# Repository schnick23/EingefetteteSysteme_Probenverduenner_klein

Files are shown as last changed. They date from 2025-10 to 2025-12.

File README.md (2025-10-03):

# Probenverdünner (Raspberry Pi + Flask)

Web-gesteuerter Probenverdünner für die Uni: Flask-Webserver auf einem Raspberry Pi steuert Pumpen, Ventile und Sensoren über GPIO. Enthält eine Hardware-Abstraktionsschicht (HAL) sowie eine Mock-Implementierung für Entwicklung ohne Pi.

## Features (MVP)
- Flask-Webserver mit REST-API und einfacher Web-UI
- Hintergrund-Tasks (Start/Stop von Verdünnungsabläufen)
- HAL: `controller` Interface, `rpi_impl` (GPIO), `mock_impl` (Simulation)
- SQLite für Protokolle (später) und Basis-Konfiguration
- systemd-Unit für Autostart auf dem Raspberry Pi

## Struktur
```
app/
  __init__.py
  main.py          # App-Factory & Serverstart
  api.py           # REST-Endpoints
  templates/
    index.html     # UI
  static/
    app.js
    style.css
  hw/
    controller.py  # Interfaces
    rpi_impl.py    # GPIO-Implementation (Pi)
    mock_impl.py   # Mock für Entwicklung
  tasks/
    runner.py      # Hintergrund-Tasks
  models.py        # (später) DB-Modelle
  config.py        # Konfig
deploy/
  raspberrypi.service  # systemd Unit
scripts/
  install_pi.sh
requirements.txt
```

## Schnellstart (lokal, ohne Pi)
```bash
python3 -m venv .venv
source .venv/bin/activate
pip install -r requirements.txt
FLASK_ENV=development python -m app.main
```
Öffne http://localhost:5000

Mock-HAL ist Standard. Umschalten auf RPi via Environment `HW_BACKEND=rpi`.

## Deployment auf Raspberry Pi (Kurz)
```bash
git clone <repo>
cd EingebetteteSysteme_Probenverduenner_klein
bash scripts/install_pi.sh
# systemd unit anpassen & aktivieren
env HW_BACKEND=rpi python -m app.main
```

## Sicherheit
- Standardmäßig keine Auth – im Labor-Netz betreiben oder Basic-Auth / Token ergänzen.
- GPIO initialisiert sichere Zustände, Fehler stoppen Tasks.

## Nächste Schritte
- Auth / Token
- Logging in Datei + Rotierung
- Echte Sensor-/Ventilsteuerung
- Verdünnungslogik (Parametrisierte Sequenzen)

## Lizenz
MIT

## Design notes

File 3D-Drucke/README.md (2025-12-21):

# 3D-Drucke

## Allgemeines

Alle 3D-Drucke für den Probenverdünbner wurden mit "ELEGOO PLA Filament 1.75mm Schwarz" gedruckt. Im Einsatz war ein Ender 3 Pro sowie ein Bambu Lab P1S.
Die Modellierung wurde in Autodesk Fusion vorgenommen, daher sind auch Fusion-Dateien mit hochgeladen, falls Änderungen an Maßen etc. gemacht werden sollen.

## Besonderheiten

Fast alle 3D-Modelle können direkt und ohne Unterbrechung gedruckt werden, bei wenigen ist es sinnvoll Support zu aktivieren. Alle Halterungen die in die Nut des Aluprofils eingeklickt werden können (u.a. Kaltgerätebuchse, Ethernet, Kabel) sind zusammengefasst in einer Fusion-Datei, jedoch als einzelne .stl-Dateien direkt druckbereit.

Eine weitere Besonderheit bildet die SpritzenkopfHalterung03.stl. In dieser Halterung sind 2 Hohlräume für Sechskant-M8-Muttern modelliert, die eingelegt werden müssen und dann im Druck "verschwinden". Um dies zu machen muss im Slicer eine Pause eingefügt werden auf der Höhe wenn der Hohlraum komplett gedruckt wurde.

## Fragen und Kontakt

Sollte es zu den Dateien oder zum 3D-Druck Fragen geben gerne per Mail an nick.schroeder@nordakademie.de oder an die anderen Teammitglieder deren Mailadressen auch auf dem Benutzerhandbuch stehen

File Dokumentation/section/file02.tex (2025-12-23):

\section{Sicherheit}
\subsection{Allgemeine Sicherheitshinweise}
Der entwickelte Probenverdünner dient ausschließlich dem zuvor beschriebenen Zweck (\autoref{ZweckDesGeraets}) der Verdünnung von Proben. Um zu prüfen, ob der Pinkler die Anforderungen der geplanten Verdünnung erfüllt, kann in \autoref{TechnischeSpezifikationen} nachgeschaut werden. Zudem sollte das Gerät nur von eingewiesenem Personal, welches entweder, durch das Lesen von diesem Dokuments oder durch eine Einweisung von bereits geschultem Personal, sich mit dem System vertraut gemacht hat. Die Technik des Geräts ist komplex und empfindlich und sollte daher nicht verändert werden. \\

Es ist wichtig, dass die Bedienungsanleitung vor der Inbetriebnahme vollständig gelesen wird. Des Weiteren ist das Gerät, nach den in \autoref{WartungUndReinigung} beschriebenen Methoden zu überprüfen, warten und reinigen. \\

Bei Schäden oder Fehlfunktionen ist das System sofort außer Betrieb zu nehmen. Hierbei ist der Not-Aus-Knopf zu betätigen(vorne rechts auf der Platte). Wie dieser zu bedienen ist folgt im nächsten Kapitel \nameref{ElektrischeSicherheitshinweise}.\\

Es dürfen nur Chemikalien verwendet werden, die mit den Materialien des Gerätes kompatibel sind (vgl. \autoref{tab:Bauteile}).

\subsection{Elektrische Sicherheitshinweise}\label{ElektrischeSicherheitshinweise}
Der Pinkler wird über ein 230V Netzteil angeschlossen und mit Strom versorgt. Nahezu die komplette Elektronik des Geräts befindet sich auf der Unterseite der Bodenplatte, siehe \autoref{fig:unten}. 

\begin{figure}[H] % r = rechts, l = links
    \centering
    
    \caption{Elektronik auf der Unterseite des Probenverdünners}
    \label{fig:unten}
\end{figure}

Deswegen sollte dieser vorsichtig auf einem stabilen, und noch wichtiger, trockenem Untergrund platziert werden. Es sollte außerdem zu jeder Zeit darauf geachtet werden, dass keine Flüssigkeiten verschüttet werden; sowohl über, als auch neben dem Gerät, da dieses, zusätzlich zu der offenen Elektronik, auch Löcher für die Kabel einiger Geräte im Boden hat.\newpage

Sollte es dazu kommen, dass der Probenverdünner im laufenden Betrieb auf einen unerwarteten Fehler stößt oder beschädigt wird, ist sofort der Not-Aus-Schalter zu tätigen, siehe \autoref{fig:notaus}. 

\begin{figure}[H] % r = rechts, l = links
    \centering
    
    \caption{Not-Aus des Probenverdünners}
    \label{fig:notaus}
\end{figure}

Nachdem dieser gedrückt wurde fährt sich sämtliche Elektronik des Geräts runter und alles bleibt dort stehen wo es ist. Um das Gerät nach dem Notfall wieder einzuschalten, muss der Not-Aus-Knopf einmal nach rechts gedreht werden.\\

Danach fährt das Gerät wieder hoch und der Zugriff auf die grafische Oberfläche ist möglich. Dort findet man den Button \textbf{Reset}, durch welchen der Probenverdünner zurück an die Nullpositionen fährt und alles resetet. Erst danach kann das Gerät wieder normal genutzt werden, siehe \autoref{fig:start}.\\

\begin{figure}[H] % r = rechts, l = links
    \centering
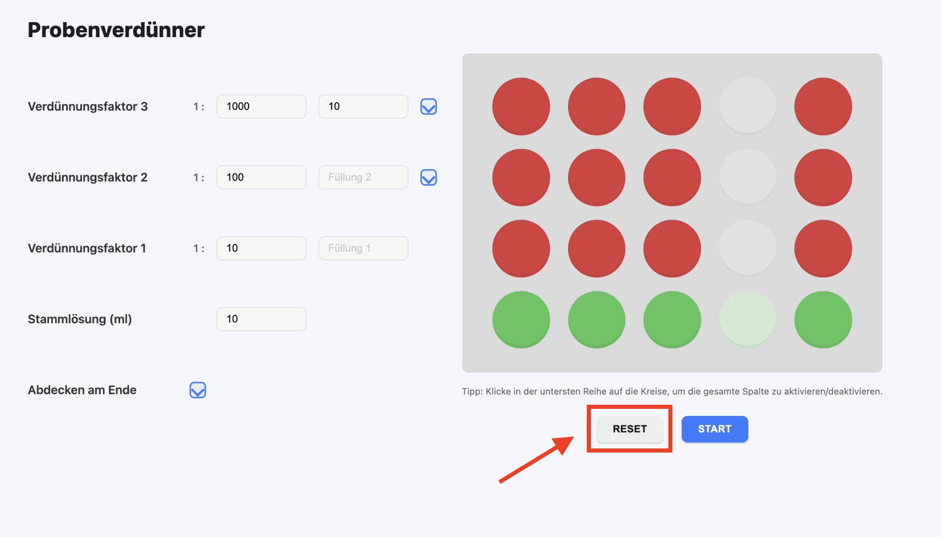
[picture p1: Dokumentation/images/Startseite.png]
    
    \caption{GUI Startseite Reset Button}
    \label{fig:start}
\end{figure}

\subsection{Mechanische Sicherheitshinweise}\label{MechanischeSicherheitshinweise}
Aus Kostengründen wurden die Füße sowie die Steckerhalter für Netzwerk und Strom 3D-gedruckt. Diese sind zwar stabil aber können bei unvorsichtiger Benutzung brechen. Sollte dies auftreten, können die nötigen Pläne, um diese erneut zu drucken, im GitHub unter dem Ordner \textit{3D-Drucke} gefunden werden. \\

Es empfielt sich das Gerät nicht zu nutzen, solange die Teile noch nicht wieder ausgetauscht wurden. \\

Leider ist der gewählte Motor, welcher den Hubtisch antreibt, nicht stark genug, um die Last der Proben zusammen mit den Widerständen, die durch das Gewinde und die Führstangen des Hubtisches entstehen, zu bewegen. Daher wurde ein Expandierseil mit Haken zur Unterstützung an dem Rahmen und dem Hubtisch befestigt.\\

Während des gesamten Durchlaufs darf nichts in dem Pinkler landen. Insbesondere der Hubtisch und die Linearführung des Spritzkopfes stellen eine Quetschgefahr dar. Deshalb sollten lange Haare, Kleidung oder Schmuckstücke von den beweglichen Teilen ferngehalten werden, um ein Verfangen zu vermeiden. \\

Zudem ist der Probenverdünner nicht für hohe Lasten geeignet. Das Gerät sollte somit nicht als Ablage oder Stütze genutzt werden.

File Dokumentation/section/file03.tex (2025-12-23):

\section{Technische Spezifikationen}\label{TechnischeSpezifikationen}
\subsection{Systemübersicht}\label{Systemuebersicht}
Die folgenden Kapitel bieten einen Überblick über die Hauptkomponenten der Maschine, deren Funktion und ihre technischen Möglichkeiten.
\subsubsection{Steuerungseinheit}
Die gesamte Technik wird mithilfe von zwei Netzteilen, ein 12-Volt- und ein 24-Volt-Netzteil, mit Strom versorgt. An das 12 Volt Netzteil ist wiederum ein Spannungswandler, welcher die passende Spannung von 5 Volt an den Raspberry Pi (Raspberry Pi 4 Model B) weiterleitet. Dieser fungiert als zentrale Steuerungseinheit. In ihm steckt eine SD Karte, auf der die Software gespeichert ist, welche die grafische Oberfläche erzeugt, sowie die Steuerungslogik, mit welcher die anderen Komponenten angesteuert werden. Eine dieser anderen Komponenten ist das Acht-Kanal-Relais, über welches die Pumpen einzeln oder zusammen angesteuert und auch hin und zurück pumpen können. Weiterhin sind an dem Pi die Driver der Stepper-Motoren angeschlossen.\\

In \autoref{fig:unten} sind alle Komponenten der Steuerungseinheit zu sehen.
\subsubsection{Linearantrieb}
Im vorherigen Kapitel wurde ein Linearmotor erwähnt, dieser ist fest an dem Linearantrieb angebracht, siehe \autoref{fig:linear}, und sorgt dafür das der Spritzkopf in Y-Richtung, entlang der großen Gewindestange, bewegt werden kann. Der Linearantrieb fährt mit einer Geschwindigkeit von maximal 50mm/s, und erreicht die gesetzten Positionen auf den Zehntelmilimeter genau. \newline

\begin{figure}[H] % r = rechts, l = links
    \centering
    
    \caption{Linearantrieb des Probenverdünners}
    \label{fig:linear}
\end{figure}
\newpage
\subsubsection{Pumpen}
Insgesamt werden in dieser Maschine fünf Pumpen verwendet, die das Verdünnungsmittel mit einem maximalen Fehler von 0,5\% auf 10ml aufziehen. Diese Pumpen werden durch das Relais-Modul gesteuert, sodass jede Pumpe einzeln angesteuert werden kann. Dies ermöglicht es einzelne Spalten zu deaktivieren. Außerdem können dadurch die minimale Abweichungen pro Pumpe ausgleichen. Im Betrieb wird jeweils in Schritten von 1ml gepumpt. Alle Pumpen starten dabei zeitgleich, aber enden zeitversetzt, sodass jede Pumpe genau 1ml gepumpt hat. An jeder Pumpe sind 2 Schläuche befestigt. Einer davon ist fest verbunden mit dem Spritzenkopf, der jeweils andere (also 5 verbleibende Schläuche) müssen vor Start des Programms in die Schottflasche gelegt werden. Diese muss zu jeder Zeit einen Mindestfüllstand von 50ml haben. \newline

\begin{figure}[H] % r = rechts, l = links
    \centering
    
    \caption{Pumpen des Probenverdünners}
    \label{fig:pumpen}
\end{figure}
\newpage
\subsubsection{Spritzenkopf}
Der Spritzenkopf ist an einem Aluprofil befestigt, welches zwischen zwei Linearführung befestigt ist. Er wird von dem Linearantrieb betrieben. An ihm sind dazu noch fünf Spritzen und Schläuche montiert, welche die Falcontubes befüllen. Die Spritzen werden über einen Steppermotor und einem 3D-gedrucktem Konstrukt gleichmäßg und gleichzeitig aufgezogen, sodass fünf oder weniger Proben gleichzeitig befüllt oder entnommen werden können. Die Spritzen arbeiten mit einem maximalen Fehler von 3\%. Zuletzt ist an dem Spritzkopf noch eine Platte befestigt, welche am Ende einer Verdünnung die Falcontubes bedecken kann.\newline

\begin{figure}[H] % r = rechts, l = links
    \centering
    
    \caption{Spritzen und Spritzenköpfe des Probenverdünners}
    \label{fig:spritzenkopf}
\end{figure}

\subsubsection{Hubtisch}
Auf dem Hubtisch befinden sich der Falcon-Tube-Ständer, ein Reinigungsbehälter, sowie ein Abfallbehälter. Im Normalfall würde dieser manuell über ein Gewinde betätigt werden. In dem Probenverdünner wird jedoch die Hoch-Runter-Bewegung über ein Stepper-Motor automatisiert und kann verschieden Positionen anfahren. Wie zuvor in \autoref{MechanischeSicherheitshinweise} erwähnt musste eine Expandierseil als zusätzliche Unterstützung des Motors implementiert werden.

\begin{figure}[H] % r = rechts, l = links
    \centering
    
    \caption{Hubtisch des Probenverdünners von vorne}
    \label{fig:Hubtischvorne}
\end{figure}

\subsubsection{Technische Möglichkeiten}\label{TechnischeMoeglichkeiten}
Der Pinkler ist in der Lage 15 Proben in unter 25 Minuten zu befüllen. Der maximale Verdünnungsfaktor beträgt 1/1000. In diesem Fall lassen sich fünf Proben verdünnen. Bei einem Verdünnungsfaktor von unter 1/100 lassen sich zehn verdünnte Proben befüllen und bei einem Verdünnungsfaktor von unter 1/10, 15. Alle Verdünnungsverhältnisse, die nicht vom Probenverdünner umgesetzt werden können, werden durch die Software abgefangen.

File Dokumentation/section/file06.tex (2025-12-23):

\section{Funktionsweise}
\subsection{Grundprinzip der Probenverdünnung}
Um eine Verdünnung von bis zu 1000-fach zu erreichen, nutzt der Probenverdünner das Prinzip der seriellen Verdünnung, bei dem eine konzentrierte Probe schrittweise mit einem Verdünnungsmittel gemischt wird, um die gewünschte Endkonzentration zu erreichen. Dabei werden präzise Mengen der Probe und des Verdünnungsmittels dosiert und in den nächsten Falcontube zusammengeführt. \\

Bei einer Verdünnung bis 10-fach wird direkt aus der Stammlösung entnommen und in die Zielprobe gegeben. Für höhere Verdünnungen wird die Probe in mehreren Schritten verdünnt, wobei jede Stufe eine weitere Verdünnung darstellt. Die zweite Reihe kann bis zu 100-fach verdünnen, indem sie die erste verdünnte Probe weiterverarbeitet. Die dritte Reihe ermöglicht schließlich eine Verdünnung bis zu 1000-fach, indem sie die bereits verdünnte Probe erneut weiter verdünnt. Auch ist es möglich, dass alle Reihen die diesselbe Verdünnung erreichen, solange genügend Stammlösung dafür vorhanden ist. Ebenfalls können auch zwei Reihen dasselbe Verdünnungsverhältnis haben und die dritte ein unterschiedliches. Verdünnungsverhältnisse, die nicht erreicht werden können, werden von der Software blockiert, um eine fehlerhafte Probenvorbereitung zu vermeiden.
\newpage
\subsection{Ablauf eines Verdünnungsvorgangs}
\begin{figure}[h!]
    \centering
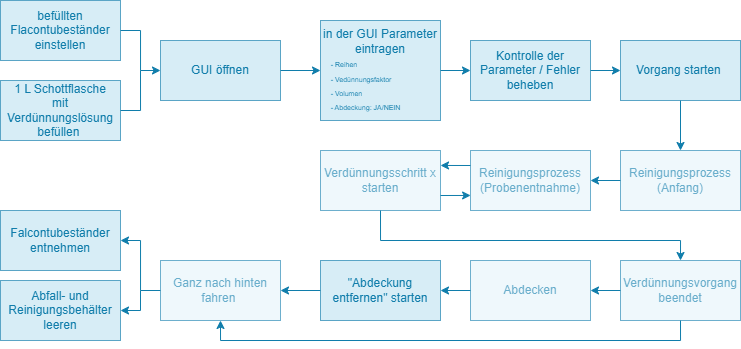
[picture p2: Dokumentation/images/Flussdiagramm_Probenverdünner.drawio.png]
    
    \caption{Ablaufdiagramm}
    \label{fig:Ablaufdiagramm}
\end{figure}

Anhand des Ablaufdiagramms in \autoref{fig:Ablaufdiagramm} wird der generelle Ablauf eines Verdünnungsvorgangs beschrieben. Zunächst muss der Falcontubeständer, die Schottflasche ggf. der Abfall- und der Reinigungsbehälter platziert werden, wie in \autoref{fig:Hubpositionierung}, \autoref{fig:Schottflaschepositionierung} und \autoref{fig:Falcontubespositionierung} zu sehen. 

\begin{figure}[H]
    \centering
    \begin{minipage}[t]{0.6\textwidth}
        \centering
        
        \caption{Positionierung der Komponenten auf dem Hubtisch}
        \label{fig:Hubpositionierung}
    \end{minipage}\hfill
    \begin{minipage}[t]{0.35\textwidth}
        \centering
        
        \caption{Positionierung der Schottflasche}
        \label{fig:Schottflaschepositionierung}
    \end{minipage}\hfill
\end{figure}

\begin{figure}[H]
    \centering
    
    \caption{Positionierung der Falcontubes}
    \label{fig:Falcontubespositionierung}
\end{figure}

Danach werden die benötigten Daten in der grafischen Oberfläche eingegeben. Dazu gehört die $"$Probenspalten-$"$ und $"$Probenreihen$"$-Auswahl, das gewünschte Verdünnungsverhältnis für jede Probe, sowie die Volumina der Stammlösungen und die gewünschten Endvolumina, siehe \autoref{fig:GUIerklaerung}. 

\begin{figure}[h!]
    \centering
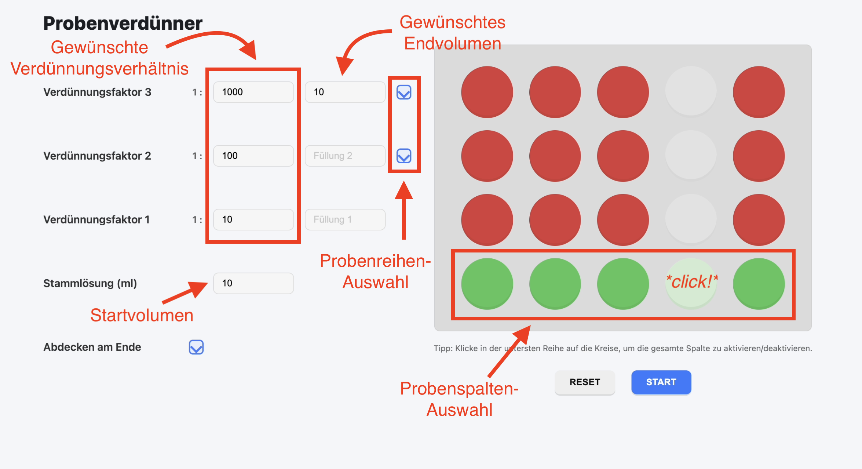
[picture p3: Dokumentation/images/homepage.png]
    
    \caption{GUI Startseite zur Eingabe der Verdünnungsparameter}
    \label{fig:GUIerklaerung}
\end{figure}

Nach der Eingabe der Daten und der Platzierung der Probenbehälter im Gerät, wird der Verdünnungsvorgang gestartet. Das System fährt zunächst die Startposition an und führt eine initiale Reinigung mit der Verdünnungslösung durch, um sicherzustellen, dass alle Schläuche und Spritzen frei von Verunreinigungen sind. \\

Daraufhin findet die Zwischenreiningung statt, indem die Spritzen die zu verdünnende Lösung plus 0.5ml aufziehen und in den Abfallbehälter entsorgen. Anschließend beginnt der eigentliche Verdünnungsschritt, bei dem die Proben entsprechend den eingegebenen Daten verdünnt werden. \\

Während des Prozesses werden auch zwischendurch Reinigungsschritte durchgeführt, um Kreuzkontaminationen zu vermeiden. Dieser Vorgang wird wiederholt, bis die letzte Verdünnung erreicht wurde. \\

Am Ende des Verdünnungsvorgangs erfolgt eine Entleerung, bei der alle Schläuche in die entgegesetze Pumprichtung Luft aufziehen. \\

Optional wird der Falcontubeständer abgedeckt, um die Proben vor Verdunstung oder Verunreinigung zu schützen. \\

Falls die Abdeckung nicht erfolgt, fährt der Spritzenkopf nach hinten in seine Anfangsposition und die Proben können manuell entnommen werden. \\

Sollten die Falcuntubes abgedeckt worden sein, muss auf der Website der Abdeckungsentfernen-Vorgang gestartet werden, siehe \autoref{fig:GUIabdeckungentfernen}, bevor die Proben entnommen werden können.

\begin{figure}[H]
    \centering
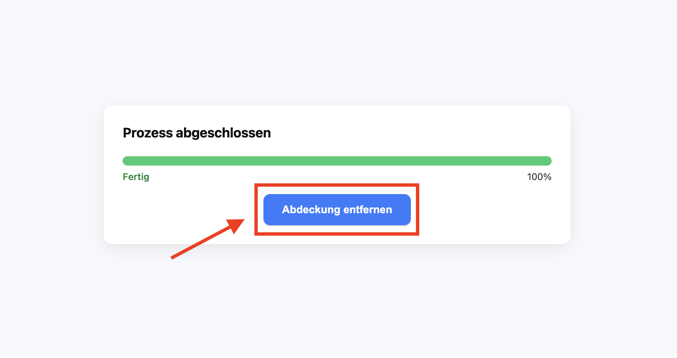
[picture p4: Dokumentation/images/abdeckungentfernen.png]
    
    \caption{GUI Abdeckungsentfernen Seite}
    \label{fig:GUIabdeckungentfernen}
\end{figure}

Zuletzt sollten der Abfall- und der Reinigungsbehälter geleert werden, um das Gerät für den nächsten Einsatz vorzubereiten.\\

Wurde der Prozess durch den Not-Aus unterbrochen, muss das System zunächst durch Drücken des Reset-Buttons in der grafischen Oberfläche zurückgesetzt werden, siehe \autoref{fig:start}. Danach kann der Ablauf von Anfang an durchgeführt werden.

\newpage
Im folgenden werden noch Ablaufdiagramme der Initialreinigung, der Zwischenreinigung und des Verdünnungsvorgangs dargestellt. Dabei ist die Reihe i, wo die Probenverdünnung stattfinden soll, und die Position wie im Code bestimmt, genauer:
\begin{itemize}
    \item \textbf{Position 1:} Abdeckungsposition
    \item \textbf{Position 2:} Reihe 1 (Stammlösung)
    \item \textbf{Position 3:} Reihe 2
    \item \textbf{Position 4:} Reihe 3
    \item \textbf{Position 5:} Reihe 4
    \item \textbf{Position 6:} Abfallbehälter
    \item \textbf{Position 7:} Reinigungsbehälter
    \item \textbf{Position 8:} Startposition (Home-Position)
\end{itemize}

\FloatBarrier
\begin{figure}[h!]
    \vspace{10mm}
    \centering
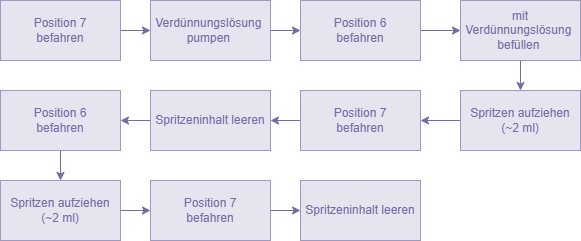
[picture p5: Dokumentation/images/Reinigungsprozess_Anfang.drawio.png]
    
    \caption{Ablaufdiagramm der Initialreinigung}
    \label{fig:AblaufdiagrammInitialreinigung}
\end{figure}

\begin{figure}[h!]
    \vspace{10mm}
    \centering
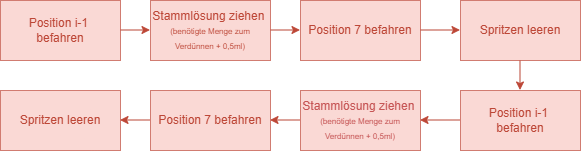
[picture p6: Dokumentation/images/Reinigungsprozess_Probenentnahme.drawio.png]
    
    \caption{Ablaufdiagramm der Zwischenreinigung}
    \label{fig:AblaufdiagrammZwischenreinigung}
\end{figure}

\begin{figure}[h!]
    \vspace{10mm}
    \centering
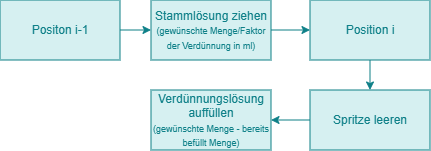
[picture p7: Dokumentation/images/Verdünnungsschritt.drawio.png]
    
    \caption{Ablaufdiagramm des Verdünnungsvorgangs}
    \label{fig:AblaufdiagrammVerdünnungsvorgang}
\end{figure}

\FloatBarrier

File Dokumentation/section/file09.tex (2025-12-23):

\section{Technische Dokumentation (Anhang)}
\subsection{Schaltplan}
\vspace{-0.8cm}
\begin{figure}[H]
    \centering
    
    \vspace{-0.75cm}
    \caption{Übersicht Schaltplan Probenverdünner}
    \label{schaltplan}
\end{figure}

\subsection{3D-Druck-Pläne}
Alle 3D-Druck-Pläne sind unter dem Ordner \href{https://github.com/schnick23/EingefetteteSysteme_Probenverduenner_klein/tree/main/3D-Drucke}{\textit{3D-Drucke}} im GitHub-Repository zu finden.

\subsection{Stückliste} \label{Materialien}
In der folgenden Tabelle sind alle im Probenverdünner verwendeten Materialien und deren Eigenschaften aufgelistet. 

\begin{longtable}{|l|l|}
        \caption{Stückliste des Probenverdünners}
        \label{tab:Bauteile}\\
        \hline
        \textbf{Bauteil} & \textbf{Bemerkungen} \\

        \hline
        \multicolumn{2}{|l|}{\textbf{Gehäuse}}\\
        \hline
        Aluprofil & 30x30mm; Länge: 440mm, 550mm; NUT 8; B-Typ\\
        Aluprofilinnenverbinder & NUT 8 \\
        Nutensteine & NUT 8 \\
        Aluplatte & 500x500mm \\

        \hline
        \multicolumn{2}{|l|}{\textbf{Linearführung}}\\
        \hline
        Linearantrieb & NEMA 23 Schrittmotor\\
        Schrittmotortreiber TB6600 & Für den NEMA 23 Schrittmotor\\
        Linearschienen & \\

        \hline
        \multicolumn{2}{|l|}{\textbf{Pumpen}}\\
        \hline
        Peristaltikpumpen & ID: 1mm, AD: 3,3mm; 12V 1,5A\\
        Relais Modul & DC 12V, 8 Kanal \\
        Schläuche & ID: 3mm, AD: 5mm; Platinvernetztes Silikonmaterial \\

        \hline
        \multicolumn{2}{|l|}{\textbf{Spritzen}}\\
        \hline
        NEMA 17 Schrittmotor & \\
        Schrittmotortreiber TMC2209 & Für den Schrittmotor NEMA 17\\
        Spritzen & 5ml; Luer-Lock-Spritzen\\
        Spritzenköpfe & 117mm; 18G\\
        Wellenkupelung & ID: 5mm und 8mm \\

        \hline
        \multicolumn{2}{|l|}{\textbf{Hubtisch}}\\
        \hline
        Hubtisch & 200x200mm; Hubhöhenbereich: 85-280mm; Max. 15kg\\
        NEMA 17 Schrittmotor & \\
        Schrittmotortreiber TMC2209 & Für den Schrittmotor NEMA 17\\
        Wellenkupelung & ID: 5mm und 8mm \\
        Expandierseil & Mit Haken; 0,6m lang \\

        \hline
        \multicolumn{2}{|l|}{\textbf{Sonstige Hardware}}\\
        \hline
        Not-Aus Knopf & \\
        Raspberry Pi 4 Model b & \\
        Endtaster & 125V 1A PDT-Grenzwert-Mikroschalter \\
        Netzteile & 12V 10A 120W; 24V 6A 150W \\
        Converter & 12V auf 5V 3A \\
        Schrauben & Dieverse Größen und Längen \\
        Muttern & Diverse Größen\\
        Litzen & Diverse Längen und Querschnitte \\
        \hline
\end{longtable}

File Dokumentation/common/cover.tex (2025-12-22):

\begin{titlepage}
\newgeometry{top=2cm, bottom=2cm, left=2cm, right=2cm}

%\definecolor{color_30879}{rgb}{0,0.12549,0.376471}

\newcommand{\stitle}{\fontsize{14}{1}\selectfont\color{NAKblue}}
\newcommand{\btitle}{\fontsize{16}{1}\selectfont\color{NAKblue}}

\centering
    %% Logo oben
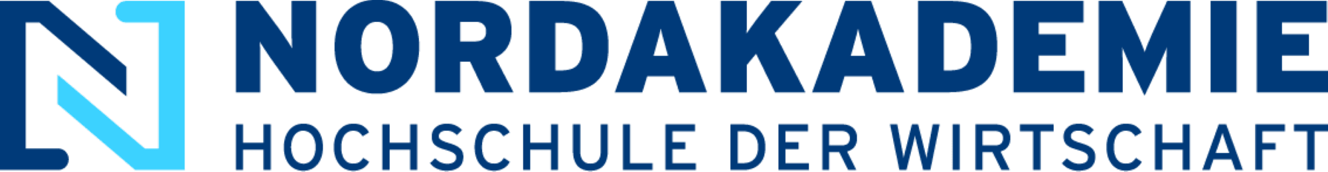
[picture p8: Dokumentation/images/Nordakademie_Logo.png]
    
    \vspace{20mm}

    \begin{spacing}{2}
        {\textbf{\fontsize{20}{1}\selectfont\color{NAKblue} Handbuch:}}\par
        {\textbf{\fontsize{18}{1}\selectfont\color{NAKblue} kleiner Probenverdünner}}\par
        \vspace{15mm}
        \textbf{{\btitle Erarbeitet von:}}\par
        {\stitle Leyna Haardt (leyna.haardt@nordakademie.de), Matrikelnummer: 12985}\par
        {\stitle Anastasia Klat (anastasia.klat@nordakademie.de), Matrikelnummer: 13275}\par
        {\stitle Max Meteling (max.meteling@nordakademie.de), Matrikelnummer: 13209}\par
        {\stitle Nick Schröder (nick.schroeder@nordakademie.de), Matrikelnummer: 13083}\par
        {\stitle Malte Wendeler (malte.wendeler@nordakademie.de), Matrikelnummer: 13105}\par
        {\stitle Studiengang: Technische Informatik}\par
        {\stitle Zenturie: T23a}\par
        \vspace{10mm}
        \textbf{{\btitle Eingebettete Systeme}}\par
        {\stitle Dozent und Prüfer:}\par
        {\stitle Prof. Dr. phil. nat. habil. Jan Haase}\par
    \end{spacing}

\renewcommand\thefootnote{}
\footnotetext{
  Zur besseren Lesbarkeit wird in dieser Hausarbeit das generische Maskulinum verwendet. Die in dieser Arbeit verwendeten Personenbezeichnungen beziehen sich - sofern nicht anders kenntlich gemacht - auf alle Geschlechter.
}

\end{titlepage}

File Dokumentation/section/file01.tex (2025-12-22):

\section{Einleitung}
\subsection{Zweck des Geräts}\label{ZweckDesGeraets}
Das vorliegende Gerät \textit{"Der Pinkler"} wurde im Rahmen eines Projektes, in Kooperation mit der Technischen Universität Bergakademie Freiberg, in dem Modul Eingebettete Systeme der NORDAKADEMIE, von den Studenten Leyna Haardt, Anastasia Klat, Max Meteling, Nick Schröder und Malte Wendeler entwickelt. Der Pinkler dient der präzisen und automatisierten Verdünnung von Proben in einem Chemielabor.
\subsection{Zielgruppe der Anleitung}
Diese Anleitung richtet sich an Laborpersonal und Techniker, die das Gerät bedienen, warten und gegebenenfalls reparieren müssen. Vorkenntnisse im Umgang mit Laborgeräten und grundlegende technische Kenntnisse sind von Vorteil.
\subsection{Kurzbeschreibung des Systems}
Das System besteht aus mehreren Hauptkomponenten, darunter ein mechanisches Gestell mit Achsen für die Bewegung eines Spritzkopfes, mehrere Pumpen zur Flüssigkeitsförderung, eine zentrale Steuerungseinheit zur Automatisierung der Prozesse, sowie eine grafische Oberfläche zur Bedienung des Geräts. Dadurch wird eine präzise, wiederholbare und zuverlässige Verdünnung von Proben ermöglicht.

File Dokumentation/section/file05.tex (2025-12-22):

\section{Erstinbetriebnahme des Probenverdünners}

\subsection{Anschluss und Start}

Für die erste Inbetriebnahme des Probenverdünners gehen Sie bitte wie folgt vor:

\begin{enumerate}
    \item Schließen Sie ein \textbf{LAN-Kabel} an den Probenverdünner an.
    \item Verbinden Sie das Gerät mit dem Stromnetz, indem Sie den \textbf{Kaltgerätestecker} einstecken.
    \item Schalten Sie den Probenverdünner über den \textbf{Netzschalter} ein.
\end{enumerate}
\begin{figure}[H] % r = rechts, l = links
    \centering
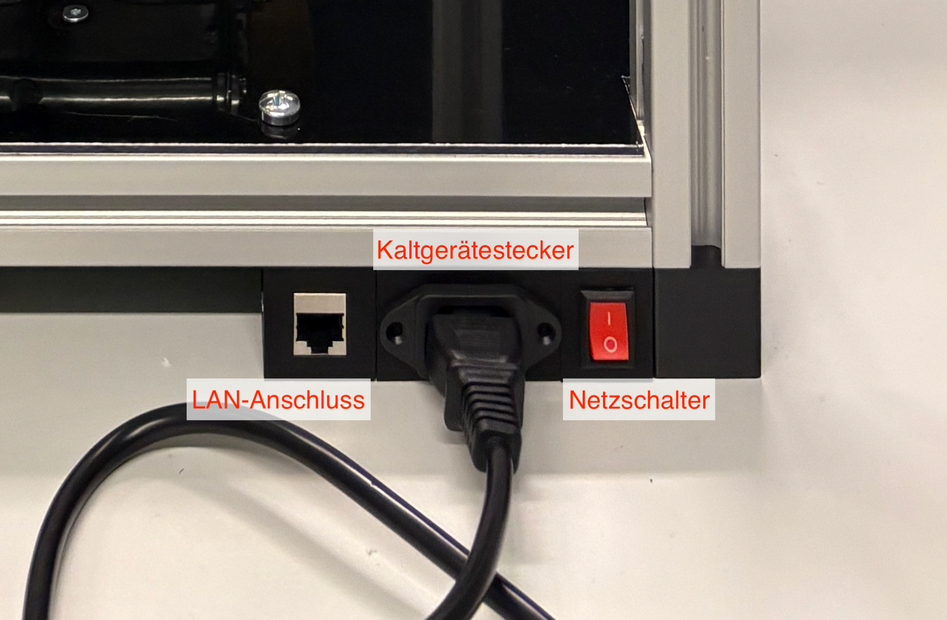
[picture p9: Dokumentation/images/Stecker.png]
    
    \caption{Anschlüsse des Probenverdünners}
    \label{fig:anschluss}
\end{figure}

Das System startet anschließend automatisch. Nach einer Hochfahrzeit von ca. \textbf{30 Sekunden} sollte das Programm vollständig laufen und der Probenverdünner im Netzwerk erreichbar sein.

\subsection{Zugriff über das Netzwerk}

Sobald das Gerät gestartet ist, kann von einem Rechner im \textbf{gleichen Netzwerk} auf den Probenverdünner zugegriffen werden.  
Empfohlen wird zunächst ein Test der SSH-Verbindung.

\subsubsection{SSH-Verbindung herstellen}\label{SSH}

Öffnen Sie auf Ihrem Rechner ein Terminal und führen Sie folgenden Befehl aus:

\begin{verbatim}
ssh pi@pinkler.local
\end{verbatim}

Das Standardpasswort lautet:

\begin{verbatim}
pi
\end{verbatim}

Wenn die Verbindung erfolgreich hergestellt werden kann, ist das Gerät korrekt im Netzwerk eingebunden.

\subsection{Einrichtung einer WLAN-Verbindung}

Nach erfolgreicher SSH-Verbindung kann optional eine WLAN-Verbindung eingerichtet werden. Dies erfolgt über die Kommandozeile mit Hilfe von \texttt{nmcli}.

\subsubsection{Schritt 1: Neue WLAN-Verbindung anlegen}

\begin{verbatim}
sudo nmcli connection add type wifi ifname wlan0 con-name tuwifi ssid "DEIN_WLAN"
\end{verbatim}

\subsubsection{Schritt 2: Sicherheit explizit festlegen (WPA2)}

\begin{verbatim}
sudo nmcli connection modify tuwifi wifi-sec.key-mgmt wpa-psk
\end{verbatim}

\subsubsection{Schritt 3: WLAN-Passwort setzen}

\begin{verbatim}
sudo nmcli connection modify tuwifi wifi-sec.psk "DEIN_PASSWORT"
\end{verbatim}

\subsubsection{Schritt 4: WLAN-Verbindung aktivieren}

\begin{verbatim}
sudo nmcli connection up tuwifi
\end{verbatim}

\subsection{Fehlerbehebung bei Nichterreichbarkeit}

Sollte der Probenverdünner nicht per SSH erreichbar sein, wenden Sie sich bitte an die zuständige \textbf{lokale IT-Abteilung}.  
Diese kann mithilfe von Netzwerkwerkzeugen (z.\,B. \texttt{nmap} oder über die Netzwerkeinstellungen) die IP-Adresse des Geräts ermitteln und gegebenenfalls einen DNS-Eintrag setzen.

\subsection{Aufruf der grafischen Benutzeroberfläche}

Nach erfolgreicher Netzwerkeinbindung kann die grafische Benutzeroberfläche (GUI) im Webbrowser aufgerufen werden:

\begin{itemize}
    \item \texttt{http://pinkler.local:5001}
    \item oder alternativ \texttt{http://IP-ADRESSE:5001}
\end{itemize}

\subsection{Überprüfung des Systemdienstes}

Falls die GUI nicht erreichbar sein sollte, stellen Sie erneut eine SSH-Verbindung her und überprüfen Sie den Status des Systemdienstes:

\begin{verbatim}
sudo systemctl status probenverduenner.service
\end{verbatim}

Falls der Dienst nicht läuft, kann er manuell gestartet werden:

\begin{verbatim}
sudo systemctl start probenverduenner.service
\end{verbatim}

\subsection{Neuinstallation der Software}

Sollte der Dienst wider Erwarten weiterhin nicht funktionieren, führen Sie bitte folgende Befehle aus, um die Software neu zu installieren:

\begin{verbatim}
cd /home/pi/EingefetteteSysteme_Probenverduenner_klein/deploy

./install.sh
\end{verbatim}

Nach Abschluss der Installation starten Sie das Gerät neu.  
In der Regel sollte der Probenverdünner anschließend wieder ordnungsgemäß funktionieren. Sollte dies nicht der Fall sein, kontaktieren Sie bitte den Support.

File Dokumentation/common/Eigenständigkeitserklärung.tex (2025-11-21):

\section{Eigenständigkeitserklärung}

Mit meiner Unterschrift versichere ich, dass ich die hier vorliegende Arbeit selbständig, ohne fremde Hilfe und nur mit den angegebenen Hilfsmitteln verfasst habe und meine Angaben zu den verwendeten Quellen der Wahrheit entsprechen und vollständig sind. Alle Quellen, aus denen ich wörtlich oder sinngemäß übernommen habe, habe ich als solche gekennzeichnet.
\vspace{05mm}
Darüber hinaus versichere ich, dass ich sämtliche Teile der vorliegenden Arbeit, die unter Zuhilfenahme künstlicher Intelligenz (KI) generiert wurden, als solche gekennzeichnet habe und deren Entstehung in einer beigefügten Prozessdokumentation nachgewiesen habe.
\vspace{05mm}
Ich habe zur Kenntnis genommen, dass zuwiderlaufendes Verhalten als Täuschungsversuch gewertet wird und zu den in der geltenden Prüfungsverfahrensordnung genannten Konsequenzen führen wird. 

\vspace{25mm}

\noindent
\begin{minipage}[t]{0.48\textwidth}
    \hrulefill
    \\
    \centering Ort, Datum\\[1.5cm]
\end{minipage}\hfill
\begin{minipage}[t]{0.48\textwidth}
    \hrulefill
    \\
    \centering Unterschrift\\[1.5cm]
\end{minipage}

\vspace{25mm}

\begin{minipage}[t]{0.48\textwidth}
    \hrulefill
    \\
    \centering Ort, Datum\\[1.5cm]
\end{minipage}\hfill
\begin{minipage}[t]{0.48\textwidth}
    \hrulefill
    \\
    \centering Unterschrift\\[1.5cm]
\end{minipage}

\vspace{25mm}

\begin{minipage}[t]{0.48\textwidth}
    \hrulefill
    \\
    \centering Ort, Datum\\[1.5cm]
\end{minipage}\hfill
\begin{minipage}[t]{0.48\textwidth}
    \hrulefill
    \\
    \centering Unterschrift\\[1.5cm]
\end{minipage}

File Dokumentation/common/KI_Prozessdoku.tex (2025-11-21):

{
% --- Helfer  für Tabelle---

\renewcommand\arraystretch{1.22}        % etwas mehr Zeilenhöhe
\setlength\extrarowheight{1.5pt}        % kleine Kopf-/Fußluft in Zellen
\renewcommand\theadfont{\bfseries\color{white}}  % Header-Schrift
\renewcommand\theadalign{cc}            % Header zentriert
% Spaltentyp P: linksbündig, automatischer Umbruch
\newcolumntype{P}[1]{>{\raggedright\arraybackslash}p{#1}}

\newcommand{\htabhead}[2][3.2cm]{%
  \multicolumn{1}{|c|}{%
    \parbox[c][2.8\baselineskip][c]{#1}{\centering\bfseries\color{white} #2}%
  }%
}

% Tabellen-Feintuning
\renewcommand\arraystretch{1.30}
\setlength{\tabcolsep}{6pt}
\setlength{\arrayrulewidth}{0.6pt}
\arrayrulecolor{NAKblue}

% makecell: Stil für Header
\renewcommand\theadfont{\bfseries\color{white}}
\renewcommand\theadalign{cc}

% --- Ende Helfer für Tabelle ---

\section{Prozessdokumentation}
\vspace{0.25em}
{\bfseries Für die Nutzung von Künstlicher Intelligenz (KI) in Prüfungs-, Transfer- und Studienleistungen\par}
\vspace{1em}

% Farben (lokal gültig durch die umschließenden { ... })
\definecolor{NAKblue}{HTML}{1F6FB2}   % Header-/Linienfarbe
\definecolor{NAKblueDark}{HTML}{154F91}
\definecolor{NAKgray}{HTML}{F2F6FA}   % optionaler Hintergrund

% Falls P noch nicht definiert ist, ENTKOMMENTIEREN:
% \usepackage{array,longtable,xcolor,colortbl}
% \newcolumntype{P}[1]{>{\raggedright\arraybackslash}p{#1}}

\begin{center}
\begin{longtable}{|P{3.2cm}|P{4.6cm}|P{4.6cm}|P{3.2cm}|}
\arrayrulecolor{NAKblue}\hline
\rowcolor{NAKblueDark}
\multicolumn{1}{|m{3.2cm}|}{\centering\bfseries\color{white} Anfrage an folgende KI* (inkl. Abrufdatum)} &
\multicolumn{1}{m{4.6cm}|}{\centering\bfseries\color{white} Grund für die Verwendung der KI} &
\multicolumn{1}{m{4.6cm}|}{\centering\bfseries\color{white} Bewertung der Qualität des KI-Outputs} &
\multicolumn{1}{m{3.2cm}|}{\centering\bfseries\color{white} Verwendete Software und Versionsnummer} \\
\hline
\endfirsthead

\arrayrulecolor{NAKblue}\hline
\rowcolor{NAKblueDark}
\multicolumn{1}{|m{3.2cm}|}{\centering\bfseries\color{white} Anfrage an folgende KI* (inkl. Abrufdatum)} &
\multicolumn{1}{m{4.6cm}|}{\centering\bfseries\color{white} Grund für die Verwendung der KI} &
\multicolumn{1}{m{4.6cm}|}{\centering\bfseries\color{white} Bewertung der Qualität des KI-Outputs} &
\multicolumn{1}{m{3.2cm}|}{\centering\bfseries\color{white} Verwendete Software und Versionsnummer} \\
\hline
\endhead

% ---- Fuß – Zwischenseiten ----
\hline
\multicolumn{4}{r}{\small Fortsetzung auf nächster Seite} \\
\endfoot

% ---- Fuß – letzte Seite ----
\hline
\endlastfoot

% ---------- TABELLENINHALT ----------
Beispiel: "kannst du mir helfen diesen Text wissenschaftlich korrekt umzuschreiben ..."  25.\,09.–16.\,10.\,2025 (durchgängig) &
Unterstützung bei der Formulierung und Strukturierung wissenschaftlicher Texte zum Thema „Software-Defined Networking (SDN)“ &
Sprachlich wissenschaftlich angemessen; Texte wurden überprüft und angepasst &
ChatGPT (Web-Version), GPT-5 \\
\hline

\end{longtable}
\end{center}

\vspace{0.75em}
\footnotesize
\noindent\textit{*Bitte formulieren Sie Ihre Anfrage und nennen Sie die verwendete KI.}
}

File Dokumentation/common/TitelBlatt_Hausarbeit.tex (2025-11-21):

\begin{titlepage}
\newgeometry{top=2cm, bottom=3cm, left=3cm, right=3cm}

\centering

% --- Titel ---
{\Large\bfseries Thema \\[1.2em]}
{\huge\bfseries
Adversarial Attacks \& Verteidigungsstrategien – von Inferenz bis Training
\par}

\vspace{3cm}
\raggedright

% --- Untertitel / Fachbereich ---
\textbf{Hausarbeit – Einführung in die KI}\\[0.5em]
an der Nordakademie – Hochschule der Wirtschaft im Studiengang Technische Informatik (Zenturie T23a)\\[3em]

% --- Autor*innen ---
\begin{tabular}{l}
\textbf{vorgelegt von:}\\[0.3em]
Malte Wendeler · Matrikel-Nr.: 13105\\[1.5em]
\textbf{und}\\[0.3em]
Anastasia Klat · Matrikel-Nr.: 13275\\
\end{tabular}

\vfill

% --- Logo ---
\begin{flushright}
  \\[1em]
\end{flushright}

% --- Datum ---
am 23.\,Mai 2025

\restoregeometry
\end{titlepage}

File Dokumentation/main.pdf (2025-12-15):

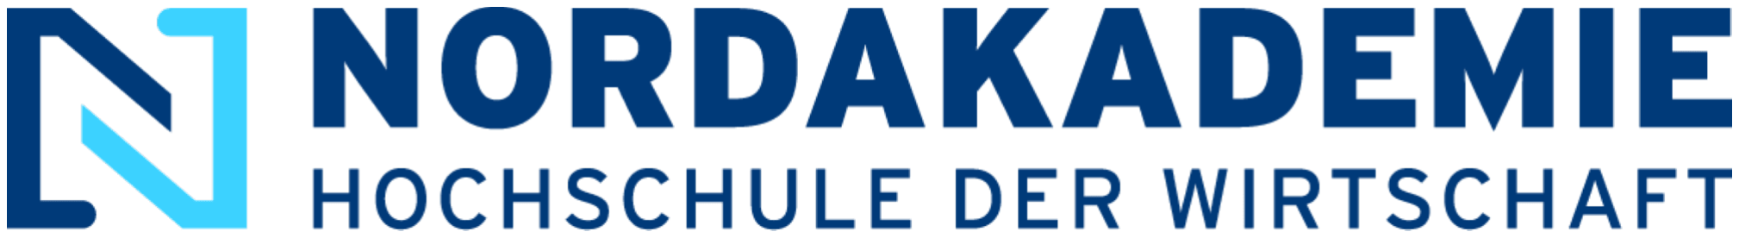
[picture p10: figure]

# Handbuch:

## kleiner Probenverdünner

## Erarbeitet von:

### Leyna Haardt, Matrikelnummer: 12985

### Anastasia Klat, Matrikelnummer: 13275

### Max Meteling, Matrikelnummer: 13209

### Nick Schröder, Matrikelnummer: 13083

### Malte Wendeler, Matrikelnummer: 13105

### Studiengang: Technische Informatik

### Zenturie: T23a

## Eingebettete Systeme

### Dozenten und Prüfer:

### Dr. habil. phil. Jan Haase

Zur besseren Lesbarkeit wird in dieser Hausarbeit das generische Maskulinum verwendet. Die in dieser Arbeit verwendeten Personenbezeichnungen beziehen sich - sofern nicht anders kenntlich gemacht - auf alle Geschlechter.

## Inhaltsverzeichnis

Abkürzungsverzeichnis | IV
1 Einleitung | 1
2 Sicherheit | 1
3 Technische Spezifikationen | 3
4 Softwarearchitektur | 5
5 Ersteinrichtung & Inbetriebnahme | 5
6 Funktionsweise | 6
7 Eingabe und Steuerung | 7
8 Wartung und Reinigung | 7

II

9 Außerbetriebnahme und Entsorgung | 8
10 Technische Dokumentation (Anhang) | 8
Eigenständigkeitserklärung | V

III

## Abkürzungsverzeichnis

IV

Einleitung

## 1 Einleitung

### 1.1 Zweck des Geräts

Das vorliegende Gerät "Hier den Namen des Geräts noch einfügen" wurde im Rahmen eines Projektes, in Kooperation mit der Technischen Universität Bergakademie Freiberg, in dem Modul Eingebettete Systeme der NORDAKADEMIE, von den Studenten Leyna Haardt, Anastasia Klat, Max Meteling, Nick Schröder und Malte Wendeler entwickelt. Der "Hier den Namen des Geräts noch einfügen" dient der präzisen und automatisierten Verdünnung von Proben in einem Chemielabor.

### 1.2 Zielgruppe der Anleitung

Diese Anleitung richtet sich an Laborpersonal und Techniker, die das Gerät bedienen, warten und gegebenenfalls reparieren müssen. Vorkenntnisse im Umgang mit Laborgeräten und grundlegende technische Kenntnisse sind von Vorteil.

### 1.3 Kurzbeschreibung des Systems

Das System besteht aus mehreren Hauptkomponenten, darunter ein mechanisches Gestell mit Achsen für die Bewegung eines Spritzkopfes, mehrere Pumpen zur Flüssigkeitsförderung, eine zentrale Steuerungseinheit zur Automatisierung der Prozesse, sowie eine grafische Oberfläche zur Bedienung des Geräts. Dadurch wird eine präzise, wiederholbare und zuverlässige Verdünnung von Proben ermöglicht.
Kurze Zusammenfassung der wichtigsten Funktionen Achsenbewegung, Pumpensteuerung, automa-tische Reinigung, Endschalter, Sicherheit

## 2 Sicherheit

### 2.1 Allgemeine Sicherheitshinweise

Der entwickelte Probenverdünner dient ausschließlich dem zuvor beschriebenen Zweck (subsection 1.1) der Verdünnung von Proben. Um zu prüfen, ob der "Name des Geräts" die Anforderungen der geplanten Verdünnung erfüllt, kann in Kapitel section 3 nachgeschaut werden. Zudem sollte das Gerät nur von eingewiesenem Personal, welches entweder, durch das Lesen von diesem Dokuments oder durch eine Einweisung von bereits geschultem Personal, sich mit dem System vertraut gemacht hat. Das Technik des Geräts ist komplex und empfindlich und sollte daher nicht verändert werden. Sollten allerdings Fehler auftreten können diese, wie in subsection 6.3 beschrieben, behoben werden. Außer derjenige Fehler ist nicht in diesem Dokument behandelt, dann sollte sich an die Entwickler des Projektes gewendet werden(Noch eine Möglichkeit zur Kontaktaufnahme angeben und hier referenzieren). Es ist wichtig, dass die Bedienungsanleitung vor der Inbetriebnahme vollständig gelesen wird. Des Weiteren

Sicherheit

ist das Gerät, nach den in section 8 beschriebenen Methoden zu überprüfen, warten und reinigen. Bei Schöden oder Fehlfunktionen ist das System sofort außer Betrieb zu nehmen.Betätigen Sie hierzu den Not-Aus-Knopf. Wie dieser zu bedienen ist folgt im nächsten Kapitel Elektrische Sicherheitshinweise.
- Nur für den vorgesehenen Zweck verwenden.
- Nur von geschultem Personal bedienen lassen.
- Vor der Inbetriebnahme Bedienungsanleitung vollständig lesen.
- Gerät nicht verändern oder umbauen.
- Gerät regelmäßig warten und überprüfen.
- Bei Schäden oder Fehlfunktionen Gerät sofort außer Betrieb - Bestimmungsgemäße Verwendung des Geräts erläutern nehmen und Fachpersonal informieren.

### 2.2 Elektrische Sicherheitshinweise

Der "Name des Geräts" wird über ein 230V Netzteil angeschlossen und mit Strom versorgt. Nahezu die komplette Elektronik des Geräts befindet sich auf der Unterseite der Bodenplatte (hier Bild der offenen Unterseite einfügen). Deswegen sollte dieser vorsichitig auf einem stabilen, und noch wichtiger, trockenem Untergrund platziert werden. Es sollte außerdem zu jeder Zeit darauf geachtet werden, dass keine Flüssigkeiten verschüttet werden; sowohl über, als auch neben dem Gerät, da dieses ,zusätzlich zu der offenen Elektronik, auch Löcher für die Kabel einiger Geräte in dem Boden hat.
Sollte es dazu kommen, dass der Probenverdünner im laufenden Betrieb auf einen unerwarteten Fehler stößt oder beschädigt wird, ist sofort der Not-Aus-Schalter zu tätigen (hier Bild des Not-Aus-Schalters einfügen). Nachdem dieser gedrückt wurde fährt sich sämtliche Elektronik des Geräts runter und alles bleibt dort stehen wo es ist. Um das Gerät nach dem Notfall wieder einzuschalten, muss der Not-Aus-Knopf einmal in die Richtung gedreht werden, die auf dem Knopf selber beschrieben ist. Danach sollte sich wie gewohnt die grafische Oberfläche öffnen. Dort findet man den Button Reset, durch welchen der Probenverdünner zurück an die Nullpositionen fährt. Bei Bedarf kann dann auch eine Reinigung initiiert werden oder Sie können die Proben dann entnehmen.
- Offene Elektronik auf Gerätunterseite
- Elektrisches Gerät –> Vorsicht im Umgang mit Flüssigkeiten.
- Not-Aus Schalter vorhanden –> Funktion und Position erläutern.

### 2.3 Mechanische Sicherheitshinweise

Aus Kostengründen mussten hinsichtlich der Mechanik an ein paar Stellen improvisiert werden. Dies führt zu wenigen Punkten die bei der Bedienung zu beachten sind. Beispielsweise wurden die Füße, sowie die Steckerhalter für Netzwerk und Strom 3D-gedruckt. Diese sind zwar stabil aber können bei unvorsichtiger Benutzung brechen. Sollte dies auftreten, können die nötigen Pläne, um diese erneut

Technische Spezifikationen

zu drucken, unter folgendem Link gefunden werden hier die 3D Drucke verlinken. Es empfielt sich das Gerät nicht zu nutzen, solange die Teile noch nicht wieder ausgetauscht wurden. Leider ist der gewählte Motor, welcher den Hubtisch antreibt, nicht stark genug, um die Last der Proben zusammen mit den Widerständen, die durch das Gewinde und die Führstangen des Hubtisches entstehen, zu bewegen. Daher wurde ein Expandierseil mit Haken zur Unterstützung an dem Rahmen und dem Hubtisch befestigt.
Während des gesamten Durchlaufs darf nichts in dem Namen des Geräts landen. Insbesondere die Linearführung des Spritzkopfes birgt eine Quetschgefahr. Zudem ist der Probenverdünner nicht für hohe Lasten geeignet. Das Gerät sollte nicht als Ablage oder Stütze genutzt werden.
- Hubtisch –> improvisierte Unterstützung
- Quetschgefahr –> während des Betriebs nicht in den Gefahrenbereich greifen oder Gegenstände platzieren (Haare, Hände etc.)
- Füße des Geräts könnten brechen –> Gerät nur auf ebenen, stabilen Untergrund stellen
- nicht dagegen lehnen oder abstützen
- Position des Not-Aus Schalters beschreiben und Funktion erläutern.
- Funktionsweise des Not-Aus Schalters erklären (z.B. Stromzufuhr unterbrechen, Maschine sofort stoppen).
- Verhalten nach Betätigung des Not-Aus Schalters erläutern (z.B. Maschine erst wieder starten, wenn Gefahr beseitigt ist).
- Wiederinbetriebnahme nach Betätigung des Not-Aus Schalters beschreiben (z.B. Reset-Knopf drücken, Maschine neu starten).

### 2.4 Chemische Sicherheitshinweise

Hinweise zum Betrieb im Laborumfeld geben.
- Material der Schläuche beachten
- Material der Spriten beachten
- Material der 3D-gedruckten Teile beachten

## 3 Technische Spezifikationen

### 3.1 Systemübersicht

Die folgenden Kapitel bieten einen Überblick über die Hauptkomponenten der Maschine, deren

Funktion und ihre technischen Möglichkeiten.

Technische Spezifikationen

### 3.1.1 Steuerungseinheit

Die gesamte Technik wird mithilfe von zwei Netzteilen, ein 12-Volt- und ein 24-Volt-Netzteil, mit Strom versorgt. Die werden wiederum über die Steckdose bestromt. An das 12 Volt Gerät ist wiederum ein Spannungswandler, welcher die passende Spannung von 5 Volt an den Raspberry Pi (Raspberry Pi 4 Model B) weiterleitet. Dieser fungiert als zentrale Steuerungseinheit. In ihm steckt eine SD Karte, auf der die Software gespeichert ist, welche die grafische Oberfläche erzeugt, sowie die Steuerungslogik, mit welcher die anderen Komponenten angesteuert werden. Eine dieser anderen Komponenten ist das Acht-Kanal-Relais, über welches die Pumpen einzeln oder zusammen angesteuert und auch hin und zurück pumpen können. Weiterhin sind an dem Pi die Driver der Stepper-Motoren und der Linearmotor selber angeschlossen.
Hier sollte noch ein Bild eingefügt oder referenziert werden auf dem die Unterseite beschriftet zu sehen ist

### 3.1.2 Linearantrieb

Im vorherigen Kapitel wurde ein Linearmotor erwähnt, dieser ist fest an dem Linearantrieb angebracht und sorgt dafür das der Spritzkopf in X-Richtung, entlang der großen Gewindestange, bewegt werden kann. Der Linearantrieb fährt mit einer Geschwindigkeit von hier die Geschwindigkeit noch angeben, und erreicht die gesetzten Positionen auf den Zehntelmilimeter genau.
Hier sollte noch ein Bild eingefügt oder referenziert werden auf dem der Linearantrieb und ihr Motor zu sehen ist.

### 3.1.3 Pumpen

Insgesamt werden in dieser Maschine fünf Pumpen verwendet, welche das Verdünnungsmittel mit einem maximalen Fehler von 0,5 % auf 10ml aufziehen. Wie gesagt werden diese über ein Relais angesteuert, sodass sie gleichzeitig pumpen. Allerdings gibt es minimale Zeitversetzungen zwischen den einzelnen Pumpen, um die gleiche Menge, somit wird jedoch die bestmögliche Genauigkeit erzeugt. An die Pumpen sind jeweils zwei Schläuche angeschlossen also insgesamt zehn. Fünf der Schläuche müssen vor Start des Programms in die Schockflasche gelegt werden, welche zu jeder Zeit einen Mindestfüllstand von 50 ml haben muss. Die anderen fünf sind an dem Spritzkopf befestigt.
Hier sollte noch ein Bild eingefügt oder referenziert werden auf dem die Pumpen beschriftet zu sehen sind

### 3.1.4 Spritzenkopf

Der Spritzenkopf ist an einem Aluprofil befestigt, welches zwischen zwei Linearführung befestigt ist. Er wird von dem Linearantrieb betrieben. An ihm sind dazu noch fünf Spritzen und Schläuche montiert, welche die Falcontubes befüllen. Die Spritzen werden über einen Steppermotor und einem 3D-gedrucktem Konstrukt gleichmäßg und gleichzeitig aufgezogen, sodass fünf Proben oder weniger

Softwarearchitektur

gleichzeitig befüllt oder entnommen werden können. Die Spritzen arbeiten mit einem maximalen Fehler von 3% auf 1 ml. Zuletzt ist an dem Spritzkopf noch eine Platte befestigt, welche am Ende einer Verdünnung die Falcontubes bedecken kann.
Hier sollte noch ein Bild eingefügt oder referenziert werden auf dem der Spritzkopf beschriftet zu sehen ist

### 3.1.5 Hubtisch

Auf dem Hubtisch befinden sich der Falcon-Tube-Ständer, ein Reinigungsbehälter, sowie ein Abfallbe-hälter. Im Normalfall würde dieser manuell über ein Gewinde betätigt werden. In dem Probenverdünner wird jedoch die Hoch-Runter-Bewegung über ein Stepper-Motor automatisiert und kann verschieden Positionen anfahren. Wie zuvor in subsection 2.3 erwähnt musste eine Expandierseil als Notlösung zur Unterstützung des Motors implementiert werden.
Hier sollte noch ein Bild eingefügt oder referenziert werden auf dem der Hubtisch beschriftet zu sehen ist

### 3.1.6 Technische Möglichkeiten

Der Name des Geräts ist in der Lage 15 Proben in 23 Minuten zu befüllen. Der maximale Verdünnungsfaktor beträgt 1/1000. In diesem Fall lassen sich fünf Proben verdünnen. Bei einem Verdünnungsfaktor von unter 1/100 lassen sich zehn verdünnte Proben befüllen und bei einem Verdünnungsfaktor von unter 1/10, 15. Alle Verdünnungsverhältnisse, die nicht vom Probenverdünner umgesetzt werden können, werden durch die Software abgefangen.

## 4 Softwarearchitektur

## 5 Ersteinrichtung & Inbetriebnahme

### 5.1 Mechanische Vorbereitung

Aufstellung
- Gerät auf ebenen, stabilen Untergrund stellen
- Platzbedarf beachten
- Orientierung des Geräts (Zugang zu Bedienelementen, Wartungspunkten) (Kontrolle beweglicher Teile)
Auf Sicherheitshinweise achten

Funktionsweise

### 5.2 Elektrische Inbetriebnahme

Anschluss an die Stromversorgung Anschlusskontrolle (Erdung, Absicherung) Anschalter tätigen

### 5.3 Netzwerkeinrichtung

LAN-Ersteinrichtung
ssh-Zugang
WLAN-Konfiguration (falls gewünscht) –> Nicks Screenshots als Code einfügen

### 5.4 Software-Initialisierung

Ersteinrichtung der Software Erststart-Prozedur

## 6 Funktionsweise

### 6.1 Grundprinzip der Probenverdünnung

Erklärung des Verdünnungsprozesses
Was passiert grundsätzlich im
(Berechnung der Verdünnungsverhältnisse, Mischvorgang)

### 6.2 Ablauf eines Verdünnungsvorgangs

Nach Eingabe der Daten, Platzierung der Proben ... Schritt-für-Schritt Beschreibung des Ablaufs Startposition anfahren
Initiale Reinigung
Verdünnungsschritt
Reinigungsschritte zwischendurch Wiederholung bis gewünschte Menge erreicht ist Endreinigung
Abschlussreinigung

Eingabe und Steuerung

Leeren der Schläuche und Spritzen Abdeckung Ja/Nein?
Wenn Ja dann fertig
Wenn Nein können Proben manuell entnommen werden
Entnehmen der Schockflasche, falls nötig –> dabei auf mögliche Reste in den Schläuchen achten

### 6.3 Fehlerfälle

Typische Fehler und deren Auswirkungen auf den Ablauf Beispiel: Probenbehälter leer, Achsenblockade
Reaktion des Systems auf Fehler
Hinweise zur Fehlerbehebung

## 7 Eingabe und Steuerung

Beim Start des Geräts wird die Hauptsteuerungssoftware automatisch geladen und die grafische Benutzeroberfläche (GUI) angezeigt. Über diese Oberfläche können alle notwendigen Parameter für

den Verdünnungsvorgang eingegeben und der Prozess gestartet werden.

### 7.1 API-Überblick

Zweck der API
Kommunikationsprinzip

### 7.2 Eingabeparameter

Anzahl der Proben
Volumen der Proben
Verdünnungsverhältnis
Startpositionen

## 8 Wartung und Reinigung

- Schläuche gelegentlich mit Reinigungsflüssigkeit durchspülen
- Spritzen ggf. austauschen –> Beschreibung wie und wo Ersatzteile zu bekommen sind und wie der Austausch funktioniert

Außerbetriebnahme und Entsorgung

- Gewinde des Spritzenkopfs, Linearführung und Hubtisch bei Bedarf reinigen und fetten
- Schockflaschen regelmäßig überprüfen und bei Bedarf austauschen
- Leeren und Reinigen des Abfallbehälters und Spritzenreingungsbehälters

## 9 Außerbetriebnahme und Entsorgung

optional
vielleicht interressanter Hinweis zur Entsorgung von elektronischen Bauteilen

## 10 Technische Dokumentation (Anhang)

### 10.1 Schaltplan

### 10.2 3D-Druck-Pläne

### 10.3 Stückliste

## Eigenständigkeitserklärung

Mit meiner Unterschrift versichere ich, dass ich die hier vorliegende Arbeit selbständig, ohne fremde Hilfe und nur mit den angegebenen Hilfsmitteln verfasst habe und meine Angaben zu den verwendeten Quellen der Wahrheit entsprechen und vollständig sind. Alle Quellen, aus denen ich wörtlich oder sinngemäß übernommen habe, habe ich als solche gekennzeichnet. Darüber hinaus versichere ich,

dass ich sämtliche Teile der vorliegenden Arbeit, die unter Zuhilfenahme künstlicher Intelligenz (KI) generiert wurden, als solche gekennzeichnet habe und deren Entstehung in einer beigefügten Prozessdokumentation nachgewiesen habe. Ich habe zur Kenntnis genommen, dass zuwiderlaufendes

Verhalten als Täuschungsversuch gewertet wird und zu den in der geltenden Prüfungsverfahrensordnung genannten Konsequenzen führen wird.

Ort, Datum | Unterschrift
Ort, Datum | Unterschrift
Ort, Datum | Unterschrift

V

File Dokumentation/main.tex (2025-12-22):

\documentclass{common/Hausarbeit}

%General stuff
\graphicspath{{images/}}
% \addbibresource{quellen.bib}

% Nak-Farben (einmalig definieren)
\definecolor{NAKblue}{RGB}{0,58,121}
\definecolor{NAKblueDark}{RGB}{0,48,100}  

\begin{document}

%Titelseite
\input{common/cover}
\newpage

% Vorspann mit römischen Seitenzahlen
\frontmatterformat

% Inhaltsverzeichnis
\renewcommand{\contentsname}{Inhaltsverzeichnis}%
\tableofcontents
\clearpage

% Verzeichnisse:
%\printfiguresintoc
%\printtablesintoc

% Abkürzungen
% \section{Abkürzungsverzeichnis}
% \input{section/Abkuerzungen}
% \newpage

\newcounter{romanlast}
\setcounter{romanlast}{\value{page}} % römische Seite merken

% Hauptteil mit arabischen Seitenzahlen
\mainmatterformat

%Sectionen hinzufügen
\foreach \i in {0,...,99}{%
  \edef\FileName{section/file\ifnum\i<10 0\fi\i.tex}% Zero-Padding + Endung
  \IfFileExists{\FileName}{\input{\FileName}}{}% <- leere ELSE-Klammer nicht vergessen!
}

\clearpage
% \backmatterformat                
% \setcounter{page}{\value{romanlast}}       % fortsetzen, wo Abkürzungen aufhören

%\printbibliography[heading=bibintoc,title=Literaturverzeichnis]
%\clearpage

%\input{common/KI_Prozessdoku}
%\clearpage

% \input{common/Eigenständigkeitserklärung}
% \clearpage

\end{document}

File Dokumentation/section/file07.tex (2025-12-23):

\section{Wartung und Reinigung}\label{WartungUndReinigung}
Um einen dauerhaft zuverlässigen, sicheren und reproduzierbaren Betrieb des Probenverdünners sicherzustellen, sind regelmäßige Pflege- und Wartungsmaßnahmen erforderlich. Diese dienen sowohl der Funktionssicherheit als auch der Vermeidung von Verschleiß, Kontaminationen und ungeplanten Ausfällen.\\

Nach Abschluss eines Verdünnungsvorgangs ist die verwendete Schottflasch aus dem Gerät zu entnehmen. Die enthaltenen Proben können je nach weiterem Arbeitsablauf entnommen oder vorübergehend unter der vorgesehenen Abdeckung im Gerät belassen werden, um sie vor äußeren Einflüssen wie Staub oder mechanischer Einwirkung zu schützen.\\

Ein besonderer Fokus der Wartung liegt auf den fluidführenden Komponenten. Schläuche sollten in regelmäßigen Abständen visuell auf Verfärbungen, Versprödung oder Undichtigkeiten kontrolliert werden. Zusätzlich empfiehlt es sich, die Schläuche gelegentlich mit einer geeigneten Reinigungsflüssigkeit durchzuspülen, um Rückstände zu entfernen und Ablagerungen sowie Kreuzkontaminationen zwischen unterschiedlichen Proben zu vermeiden.\\

Auch die verwendeten Spritzen unterliegen einem natürlichen Verschleiß. Bei schwergängigem Lauf, sichtbaren Beschädigungen oder Undichtigkeiten sind diese auszutauschen. Der Austausch erfolgt durch Lösen der mechanischen Fixierung am Spritzenhalter, das vorsichtige Entfernen der alten Spritze sowie das anschließende Einsetzen und sichere Befestigen der neuen Spritze. Nach dem Austausch ist eine Funktionsprüfung durchzuführen, um einen korrekten Sitz und eine einwandfreie Förderbewegung sicherzustellen. Zu der Funktionsprüfung gehört auch sicherzustellen, dass die neuen Spritzen auch kompatibel mit den eingestellten Positionen sind. Dazu kann das Skript\;\texttt{positionen\_messen.py}\;genutzt werden, welches nur über eine SSH-Verbindung (\autoref{SSH}) und Konsolenaufruf folgendermaßen gestartet werden kann:

\begin{verbatim}
cd /home/pi/EingefetteteSysteme_Probenverduenner_klein/scripts/

python3 positionen_messen.py

hub 

h

lin

h

w 

# Schrittanzahl
\end{verbatim}
Um die einzelnen Positionen zu testen, müssen folgende Anzahl an Schritten, von der Home-Possition, ausgeführt werden:\\

\begin{table}[H]
    \centering
    \begin{tabular}{||ll||ll||}
        \hline
        \hline
        Home Position & 0 & 2. Verdünnungsreihe & 50300 \\
        Abfallbehälter & 22300 & 1. Verdünnungsreihe & 61800 \\
        Reinigungsbehälter & 30300 & Reihe 0 (Stammlösung) & 73300 \\
        3. Verdünnungsreihe & 38300 & Abdeckungsposition & 95000 \\
        \hline
        \hline
    \end{tabular}
\end{table}

{\color{red}{Bei diesem Skript ist der vordere Endtaster deaktiviert. Nach jedem Vorwärtsschritt ist durch $h$ zu homen. Im Notfall kann durch \textbf{\texttt{strg + c}} abgebrochen werden. Der Hubtisch muss vor dem Start auch in der Home-Position stehen (ganz unten).}}\\

Mechanische Komponenten wie das Gewinde des Spritzenkopfs, die Linearführungen sowie der Hubtisch sind regelmäßig auf Verschmutzungen zu prüfen. Bei Bedarf sind diese zu reinigen und mit einem geeigneten Schmier- oder Gleitmittel leicht zu fetten, um einen gleichmäßigen, verschleißarmen Bewegungsablauf zu gewährleisten. Dabei ist darauf zu achten, dass keine Schmierstoffe in den Probenbereich oder in fluidführende Bauteile gelangen.\\

Darüber hinaus sind der Abfallbehälter sowie der Spritzenreinigungsbehälter regelmäßig zu leeren und gründlich zu reinigen. Dies verhindert Geruchsbildung, Verunreinigungen und das unbeabsichtigte Vermischen von Rückständen unterschiedlicher Proben. Alle mit Flüssigkeiten in Kontakt kommenden Behälter sollten nach der Reinigung vollständig trocknen, bevor sie erneut eingesetzt werden.\\

Abschließend ist eine regelmäßige Sichtprüfung der elektrischen und mechanischen Gesamtstruktur des Probenverdünners empfehlenswert. Dabei sollten Kabel, Steckverbindungen und Befestigungselemente auf festen Sitz und unbeschädigten Zustand überprüft werden. Durch die konsequente Durchführung der beschriebenen Pflege- und Wartungsmaßnahmen kann ein stabiler, präziser und langlebiger Betrieb des Probenverdünners sichergestellt werden.

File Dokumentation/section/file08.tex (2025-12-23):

\section{Außerbetriebnahme und Entsorgung}

Das Gerät darf nicht im normalen Hausmüll entsorgt werden. Stattdessen sollten die Elektronikabfälle zu einer geeigneten Sammelstelle für Elektronikabfälle gebracht werden, um eine umweltgerechte Entsorgung sicherzustellen. Die Schläuche und Spritzen sollten vor der Entsorgung gereinigt und entleert werden. Der Rahmen sowie andere nicht-elektronische Teile können gemäß den Vorschriften für Metallabfälle entsorgt werden. Bevor Kabel oder andere elektronische Komponenten entfernt werden, muss sichergestellt werden, dass das Gerät vollständig vom Stromnetz getrennt ist.

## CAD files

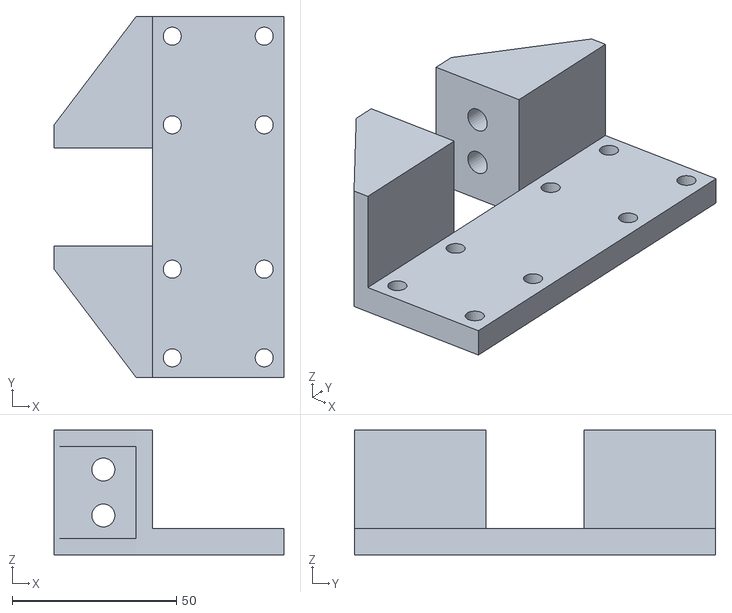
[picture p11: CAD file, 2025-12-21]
3D-Drucke/VerbinderLinearfuehrung_Querbalken.stl
70.0 x 110.0 x 38.0

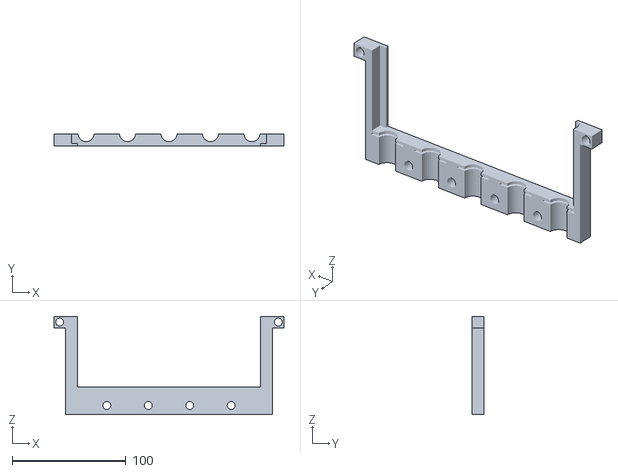
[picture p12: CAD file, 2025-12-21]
3D-Drucke/SpritzenkopfHalterung02.stl
202.5 x 11.0 x 86.4

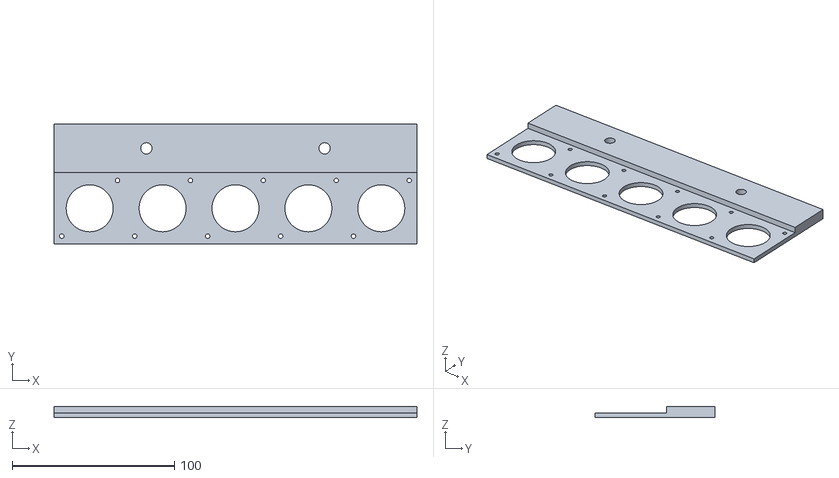
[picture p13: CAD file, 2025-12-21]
3D-Drucke/Pumpenhalterung.stl
224.0 x 74.0 x 7.00

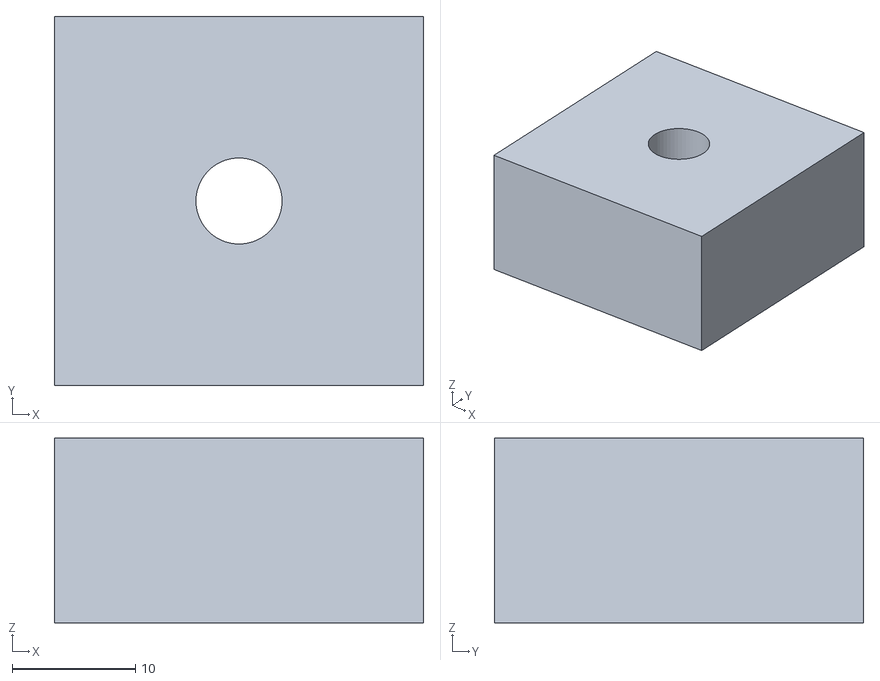
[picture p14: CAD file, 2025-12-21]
3D-Drucke/SpacerAbdeckplatte.stl
30.0 x 30.0 x 15.0

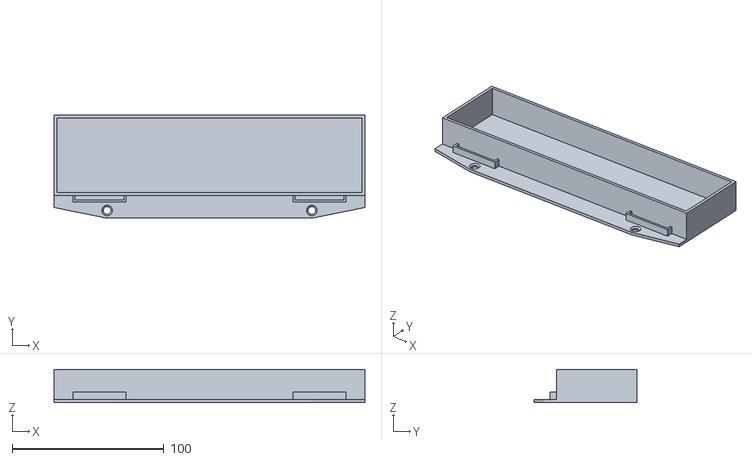
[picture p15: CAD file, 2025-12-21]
3D-Drucke/FalconTubeStaenderHalterung01.stl
205.0 x 68.0 x 22.0

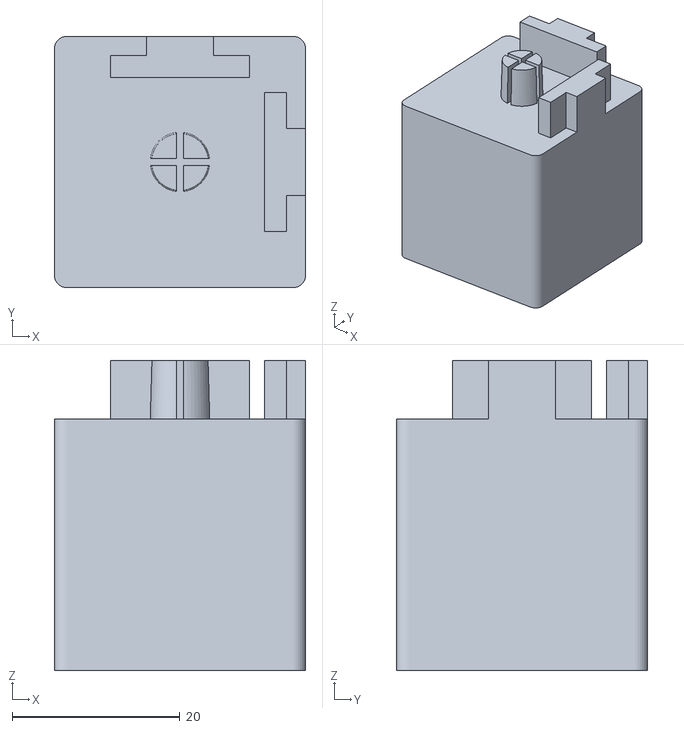
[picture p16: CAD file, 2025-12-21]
3D-Drucke/Fuß_30mm.stl
30.0 x 30.0 x 37.0

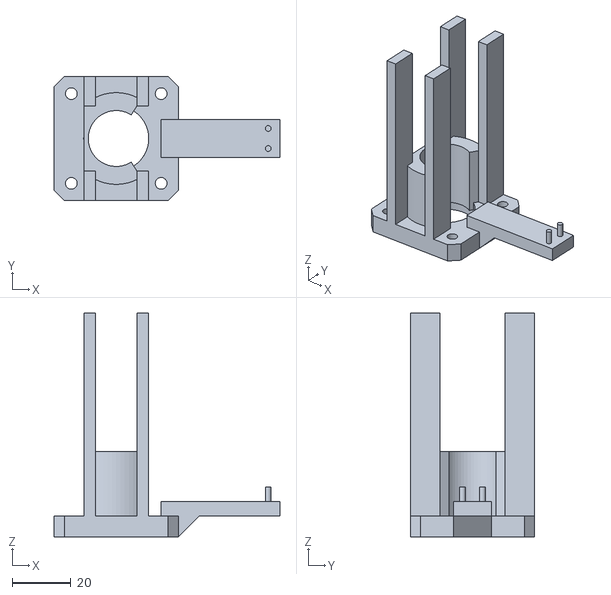
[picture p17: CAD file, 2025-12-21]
3D-Drucke/HubtischMotorHalterung.stl
76.8 x 42.3 x 76.0

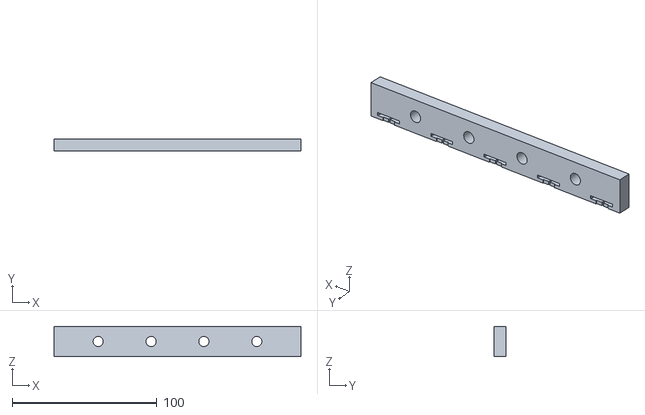
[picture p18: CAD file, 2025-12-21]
3D-Drucke/SpritzenkopfHalterung04.stl
170.5 x 8.00 x 20.8

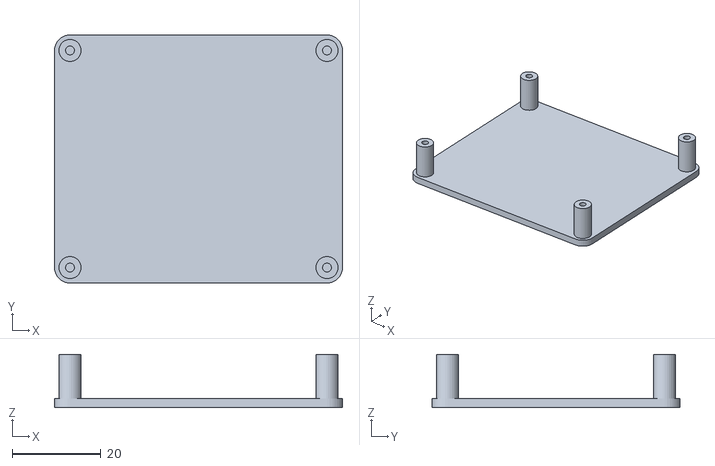
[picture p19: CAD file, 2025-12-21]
3D-Drucke/PiHalterung.stl
65.0 x 56.0 x 12.0

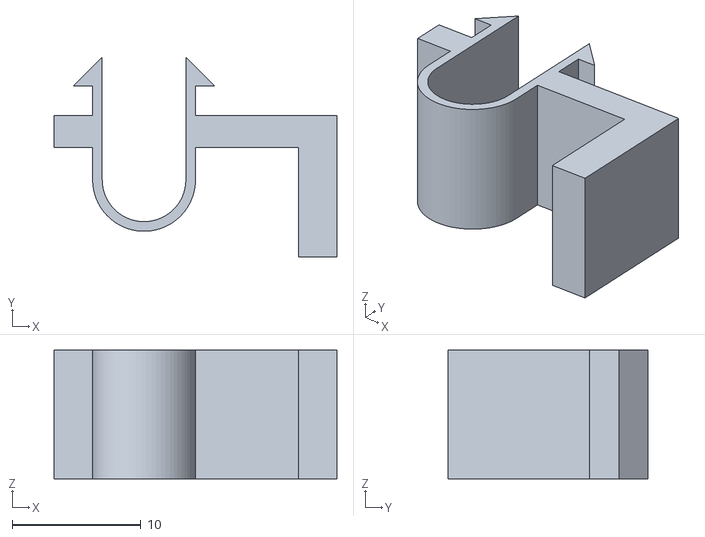
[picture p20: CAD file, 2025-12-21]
3D-Drucke/Halterung11mmEndtasterSpritzenkopf.stl
22.0 x 15.6 x 10.0

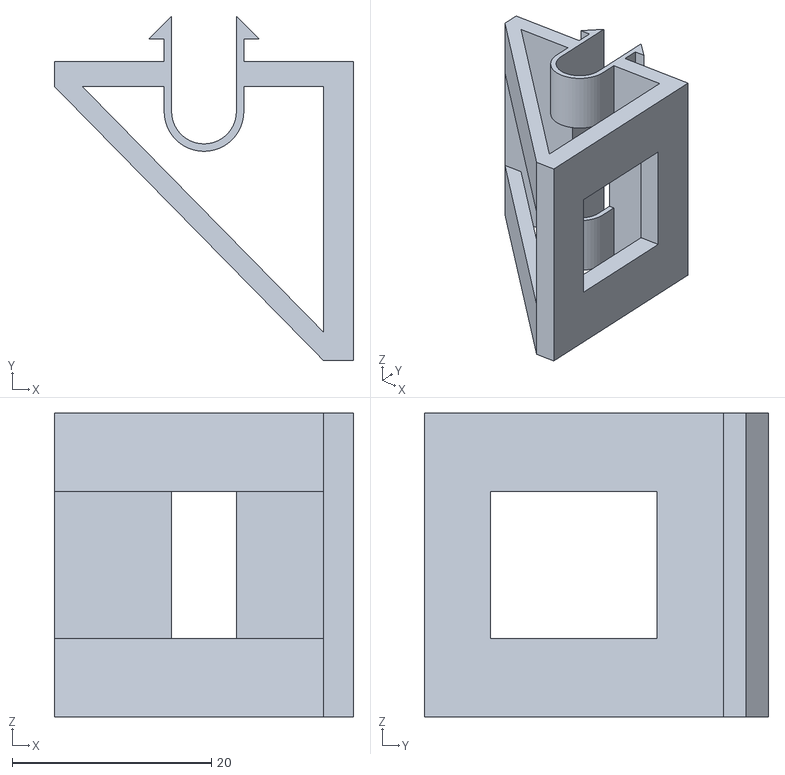
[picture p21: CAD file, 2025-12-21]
3D-Drucke/HalterungEthernetKupplung.stl
30.0 x 34.6 x 30.5

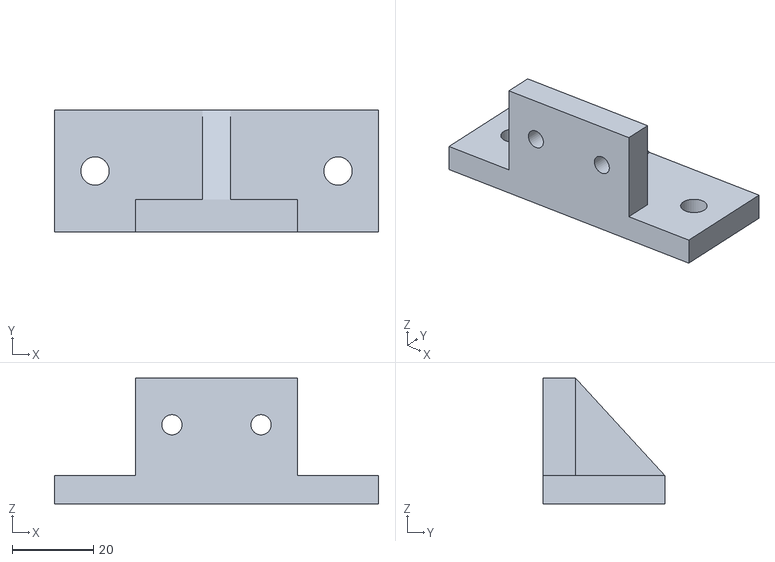
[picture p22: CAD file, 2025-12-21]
3D-Drucke/HalterungLinearfuehrung.stl
80.0 x 30.0 x 31.0

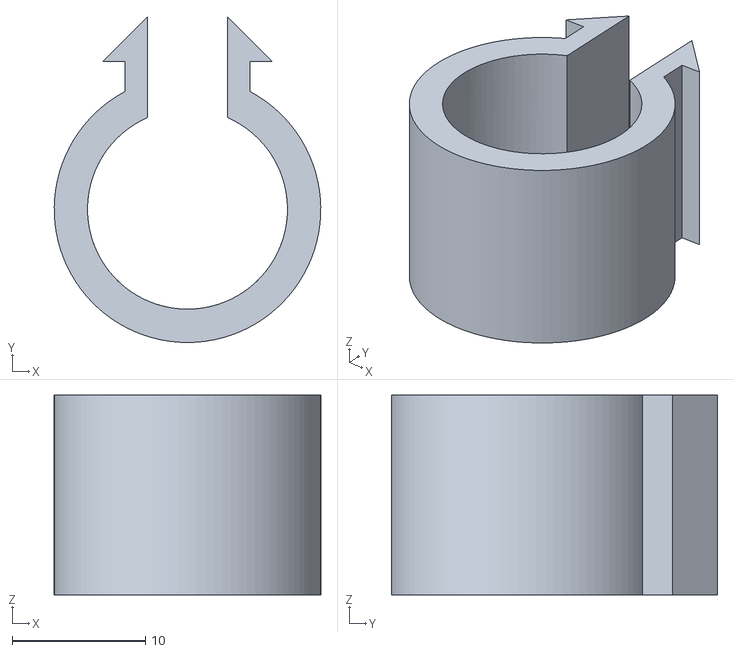
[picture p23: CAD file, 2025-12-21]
3D-Drucke/HalterungKabel.stl
20.0 x 24.5 x 15.0

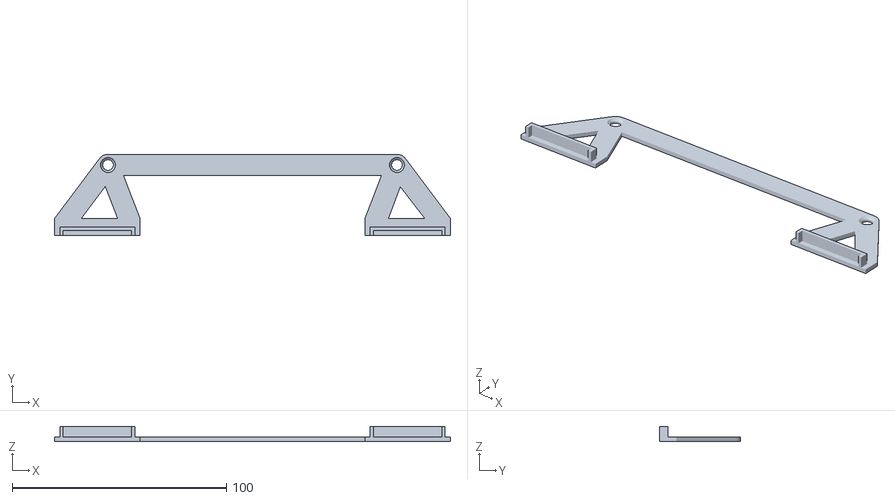
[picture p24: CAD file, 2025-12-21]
3D-Drucke/FalconTubeStaenderHalterung02.stl
185.0 x 38.0 x 7.00

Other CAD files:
3D-Drucke/SpritzenkopfHalterung01.stl
3D-Drucke/HalterungLinearantrieb.stl
3D-Drucke/SchottflaschenHalterung.stl
3D-Drucke/VerbindungMotorisierteLinearfuehrungQuerprofil.stl
3D-Drucke/Abdeckplatte.f3d
3D-Drucke/Abdeckplatte.stl
3D-Drucke/Auffangbehaelter.f3d
3D-Drucke/Auffangbehaelter.stl
3D-Drucke/EinklickbareHalterungen.f3d
3D-Drucke/EndtasterHalter.f3d
3D-Drucke/EndtasterHalter.stl
3D-Drucke/FalconTubeStaenderHalterung.f3d
3D-Drucke/HalterungKaltgeraetebuchse.stl
3D-Drucke/HalterungKippschalter.stl
3D-Drucke/HalterungLinearantrieb.f3d
3D-Drucke/HalterungLinearfuehrung.f3d
3D-Drucke/HalterungenSpritzenkopf.f3z
3D-Drucke/HubtischMotorHalterung.f3d
3D-Drucke/Kabelbinderhalter.f3d
3D-Drucke/Kabelbinderhalter.stl
3D-Drucke/PiHalterung.f3d
3D-Drucke/Profilendkappe_2mm.stl
3D-Drucke/Profilendkappe_8mm.stl
3D-Drucke/ProfilendkappenUNDFueße.f3d
3D-Drucke/Pumpenhalterung.f3d
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

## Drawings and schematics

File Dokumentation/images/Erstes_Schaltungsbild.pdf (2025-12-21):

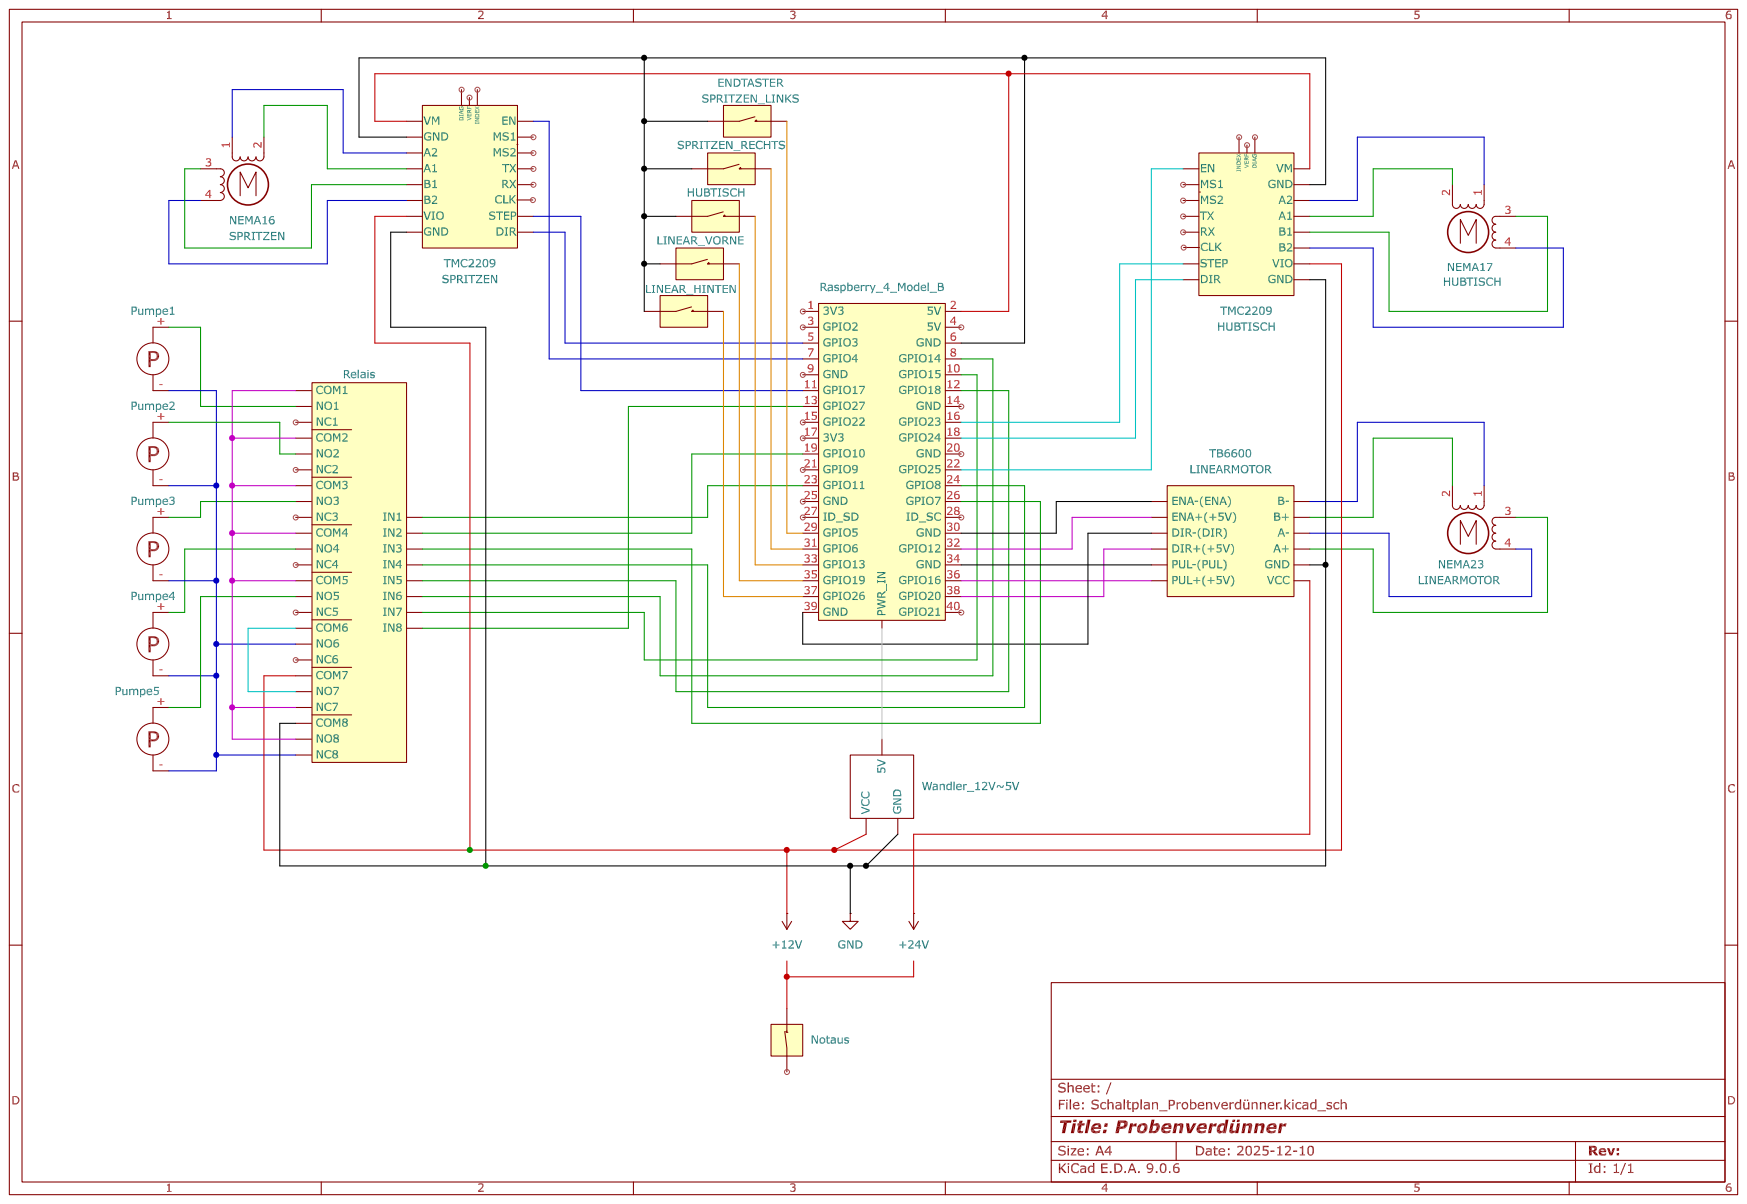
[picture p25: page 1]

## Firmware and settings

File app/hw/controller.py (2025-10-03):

from abc import ABC, abstractmethod
from typing import Dict, Any
import time

class HardwareError(Exception):
    pass

class HardwareInterface(ABC):
    @abstractmethod
    def initialize(self) -> None:
        ...

    @abstractmethod
    def start_pump(self, pump_id: str, speed: float = 1.0) -> None:
        ...

    @abstractmethod
    def stop_pump(self, pump_id: str) -> None:
        ...

    @abstractmethod
    def set_valve(self, valve_id: str, position: int) -> None:
        ...

    @abstractmethod
    def read_sensor(self, sensor_id: str) -> float:
        ...

class MockHardware(HardwareInterface):
    def __init__(self):
        self._pumps = {}
        self._valves = {}
        self._sensors = {"temp": 22.5, "level": 0.0}

    def initialize(self) -> None:
        pass

    def start_pump(self, pump_id: str, speed: float = 1.0) -> None:
        self._pumps[pump_id] = speed

    def stop_pump(self, pump_id: str) -> None:
        self._pumps.pop(pump_id, None)

    def set_valve(self, valve_id: str, position: int) -> None:
        self._valves[valve_id] = position

    def read_sensor(self, sensor_id: str) -> float:
        base = self._sensors.get(sensor_id, 0.0)
        # simple fluctuation
        return base + (time.time() % 5) * 0.01

    def debug_state(self) -> Dict[str, Any]:
        return {"pumps": self._pumps, "valves": self._valves}

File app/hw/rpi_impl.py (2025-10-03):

from typing import Any
try:
    from gpiozero import LED  # Platzhalter für echte Aktoren
except ImportError:  # Falls lokal ohne Pi
    LED = None  # type: ignore

from .controller import HardwareInterface, HardwareError

class RPiHardware(HardwareInterface):
    def __init__(self):
        self._initialized = False
        self._pump_led = None

    def initialize(self) -> None:
        if LED is None:
            raise HardwareError("gpiozero nicht verfügbar – auf einem Raspberry Pi ausführen")
        # Beispiel: LED als Stellvertreter für Pumpe
        self._pump_led = LED(17)  # type: ignore
        self._initialized = True

    def start_pump(self, pump_id: str, speed: float = 1.0) -> None:
        if not self._initialized:
            raise HardwareError("Hardware nicht initialisiert")
        if self._pump_led:
            self._pump_led.on()

    def stop_pump(self, pump_id: str) -> None:
        if self._pump_led:
            self._pump_led.off()

    def set_valve(self, valve_id: str, position: int) -> None:
        # TODO: Implementieren abhängig vom Ventiltyp
        pass

    def read_sensor(self, sensor_id: str) -> float:
        # TODO: Implementieren (ADC etc.)
        return 0.0


def get_hardware() -> HardwareInterface:
    hw = RPiHardware()
    hw.initialize()
    return hw

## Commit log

2025-10-05 Vorbereitung GPIO Steuerung und State-Messages
2025-10-05 Vorbereitung GPIO Steuerung und State-Messages 2
2025-11-27 Create stepper.py
    kurzes, vereinfachtes Skript für die Ansteuerung und Kontrolle des Stepper Motors. Einige Variablen müssen noch ersetzt werden
2025-11-27 gewünschte füllmenge und kisten disablen
2025-11-28 Update stepper.py
    Änderung zu passendem Skript
2025-11-29 check seite und index seite update
2025-12-05 paar skripte fuer stepper
2025-12-07 Update motorcontroller.py
    Hinzufügen von _set_dir_ Funktion für Motor-Dreh-Richtung
2025-12-13 Pumpenskripte anpepasst; Funktion zum Messen der Positionen; home-Methoden vereinheitlicht
2025-12-13 Pin Belegung
2025-12-13 pumpentest zum saubermachen
2025-12-14 pumpen justier skript
2025-12-14 fix pumpen dings
2025-12-14 Umstrukturierung und überflüssiges weg
2025-12-14 Anpassung der Gliederung im LateX Projekt
2025-12-14 pump it up
2025-12-14 speed per axis; change di improvement
2025-12-14 homing der lin achse ohne beschleunigungs rampe; hinzufügen von step_linear in motorcontroller
2025-12-14 small fix linear homing
    [LinearFuehrung.py]
2025-12-14 Funktion Xml pumpen
2025-12-21 Upload 3D Druck-Dateien als .stl und FusionDateien
    [Abdeckplatte.f3d, Abdeckplatte.stl, Auffangbehaelter.f3d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]
2025-12-21 Create README.md for 3D printing documentation
    Added README.md with details on 3D printing projects.
2025-12-22 mehr bilder und korrektur
